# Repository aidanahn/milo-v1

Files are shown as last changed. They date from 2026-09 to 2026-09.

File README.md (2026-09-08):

# pacer-v1
A 3D-printed, 1/10-scale autonomous pacer robot for track and field.

## Videos
https://github.com/user-attachments/assets/b290baa9-71bd-49d5-837f-d4e4456bcb18

https://github.com/user-attachments/assets/f611f2c6-a903-4dcb-a009-24ee0bf0cf6d

## Bill of Materials
| Quantity | Part Name |
|:---:|---|
| 16 | 10x15x4mm Bearing |
| 2 | 5x10x4mm Bearing |
| 4 | M3 Tie Rod End |
| 1 | 35kg Servo |
| 1 | Servo Horn |
| 1 | Sensored Brushless DC Motor |
| 4 | Wheels |
| 1 | LiPo Battery |
| 1 | 120mm Timing Belt |
| 1 | 20T GT2 Timing Pulley |
| 1 | 40T GT2 Timing Pulley |
| 4 | 55mm Touring Shocks |
| 1 | Differential |
| 1 | Pinion Gear |
| 1 | Breadboard |
| 1 | ESP32-S3-DevKitC-1-N8R8 |
| 1 | Power Distribution Module |
| 1 | 5V Buck Converter |
| 1 | AS5600 |
| 1 | Diametrically Magnetized On-Axis Magnet |
| 1 | XT60 to T-Plug Adapter |
| 33 | Jumper Wires |
| 1 | 5V Buck Converter |
| | PETG Filament |
| | Differential Oil |
| | Shock Oil |

## Fastener List
| Type | Size | Length | Head | Quantity |
|---|---|---|---|---|
| Screw | M2 | 8mm | Button Head | 4 |
| Washer | M2 | | | 4 |
| Screw | M3 | 4mm | Socket Head | 10 |
| Screw | M3 | 8mm | Socket Head | 2 |
| Screw | M3 | 12mm | Socket Head | 21 |
| Screw | M3 | 16mm | Socket Head | 20 |
| Screw | M3 | 20mm | Socket Head | 6 |
| Screw | M3 | 25mm | Socket Head | 13 |
| Screw | M3 | 30mm | Socket Head | 1 |
| Screw | M3 | 35mm | Socket Head | 10 |
| Screw | M3 | 8mm | Button Head | 2 |
| Screw | M3 | 12mm | Button Head | 7 |
| Screw | M3 | 16mm | Button Head | 9 |
| Rod | M3 | 50mm | | 1 |
| Rod | M3 | 200mm | | 1 |
| Rod | M3 | | | 11 |
| Washer | M3 | | | 6 |
| Set Screw | M3 | | | 2 |
| Screw | M4 | 20mm | Socket Head | 4 |
| Nylon Locknut | M4 | | | 4 |

## License
This work is licensed under a [MIT License](LICENSE).

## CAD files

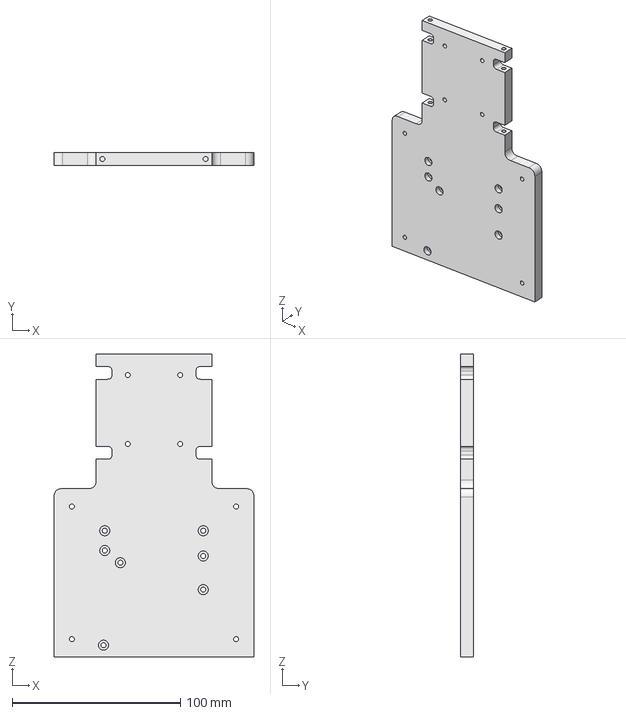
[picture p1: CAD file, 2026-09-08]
cad/chassis/front_plate.step
118.8 x 7.50 x 180.0 mm

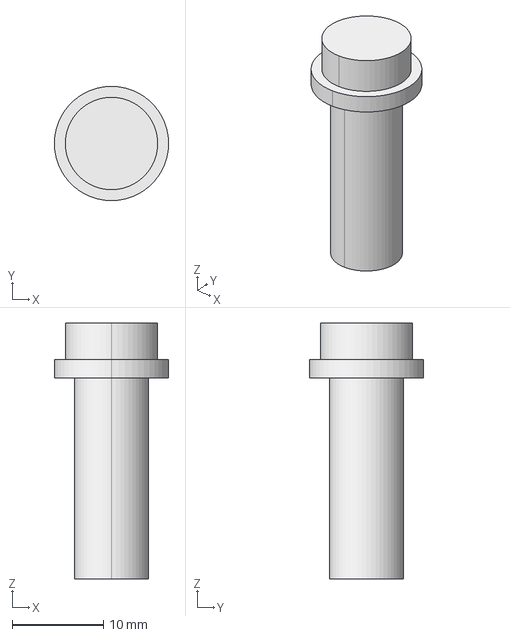
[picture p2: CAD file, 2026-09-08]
cad/drivetrain/shaft_coupling.step
12.5 x 12.5 x 28.0 mm

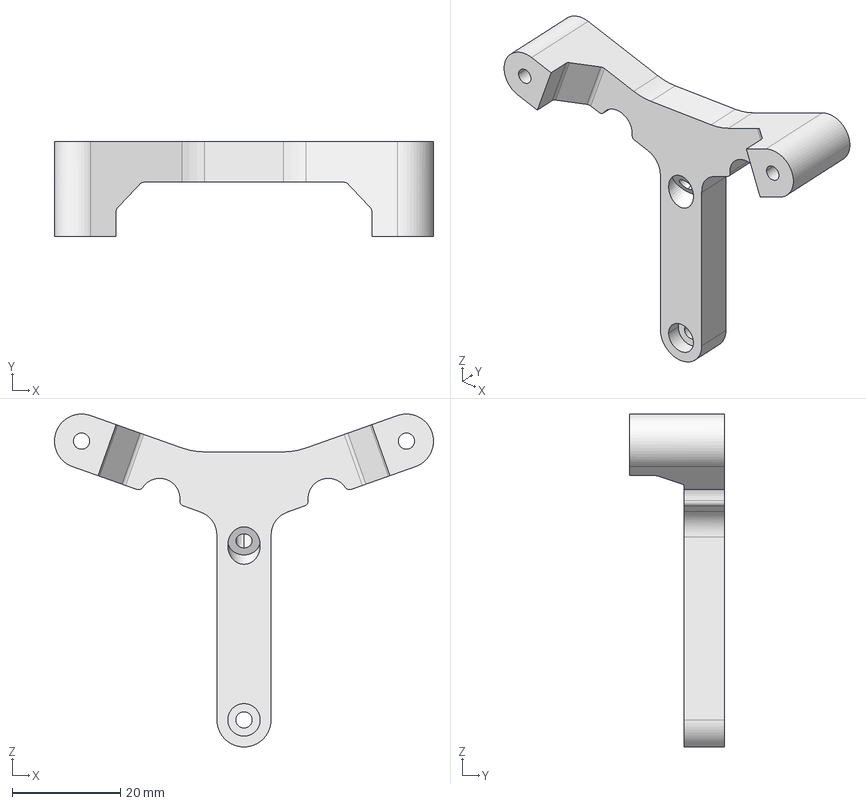
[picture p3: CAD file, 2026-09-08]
cad/sensors/sensor_arm.step
70.0 x 17.5 x 61.5 mm

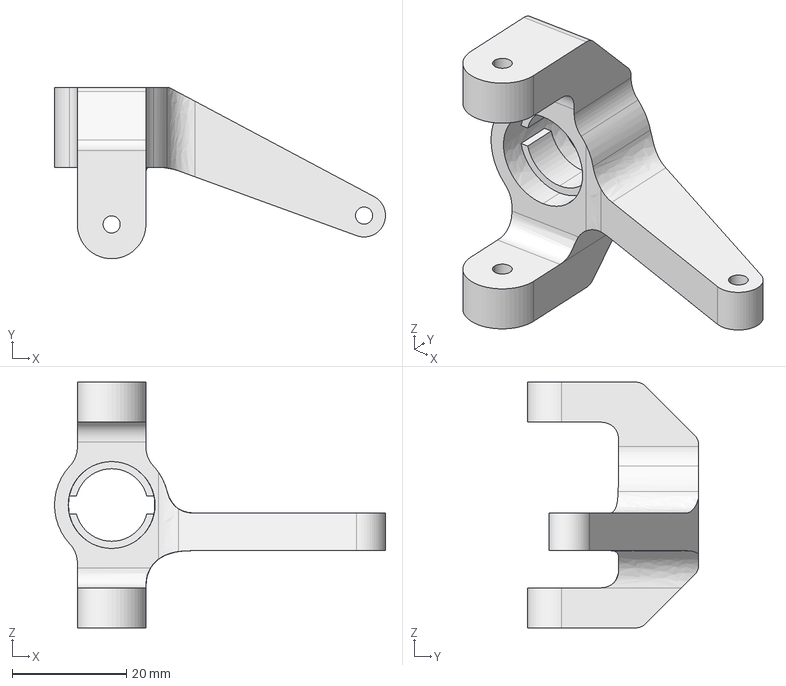
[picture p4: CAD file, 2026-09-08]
cad/steering/right_steering_knuckle.step
57.9 x 30.0 x 43.0 mm

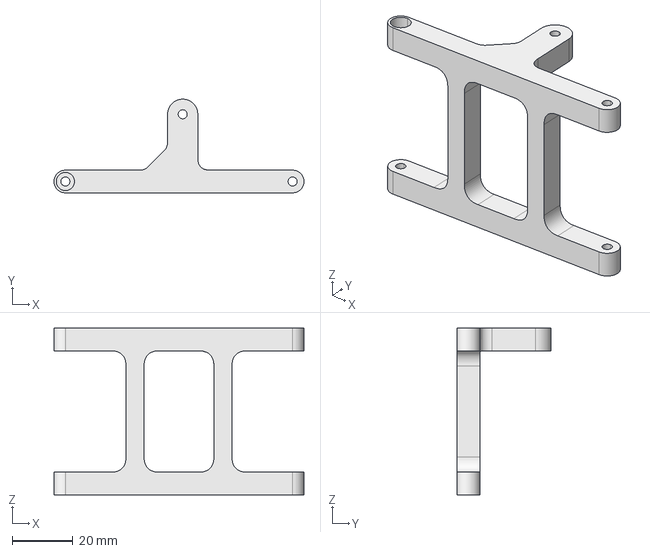
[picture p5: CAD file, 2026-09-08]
cad/suspension/rear_right_lower_control_arm.step
82.5 x 30.9 x 55.0 mm

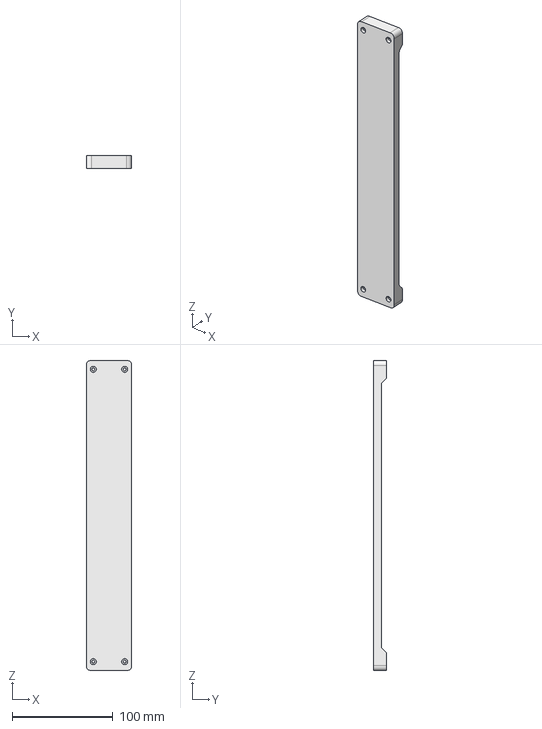
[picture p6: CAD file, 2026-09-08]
cad/chassis/electronics_bed.step
45.0 x 13.0 x 307.5 mm

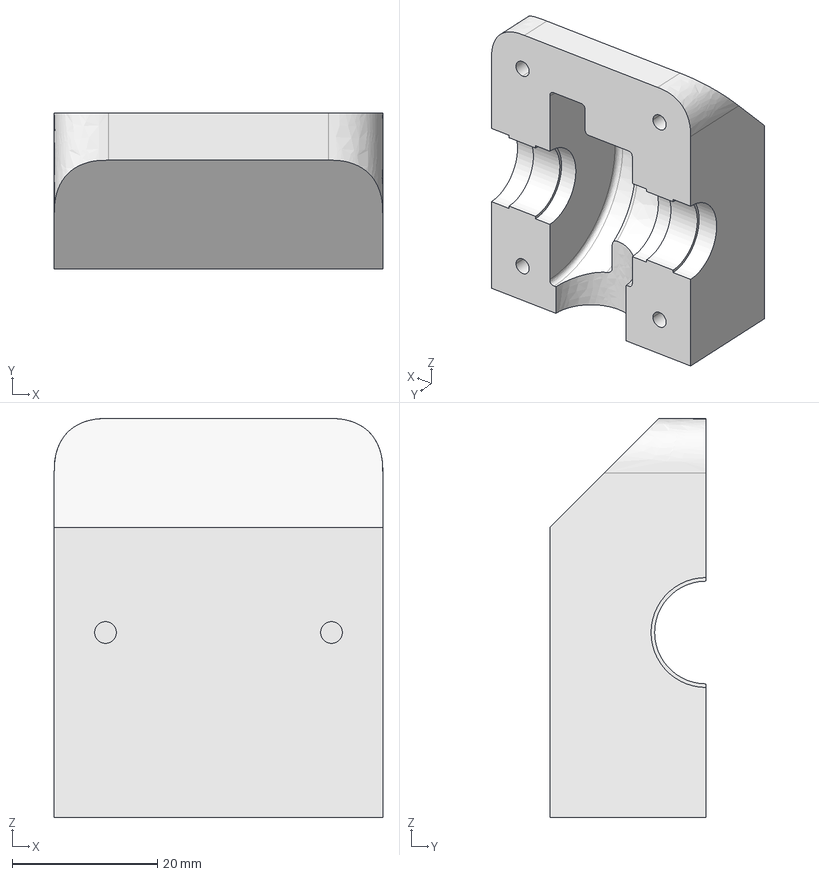
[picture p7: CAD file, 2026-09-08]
cad/drivetrain/upper_differential_case.step
45.3 x 21.5 x 55.0 mm

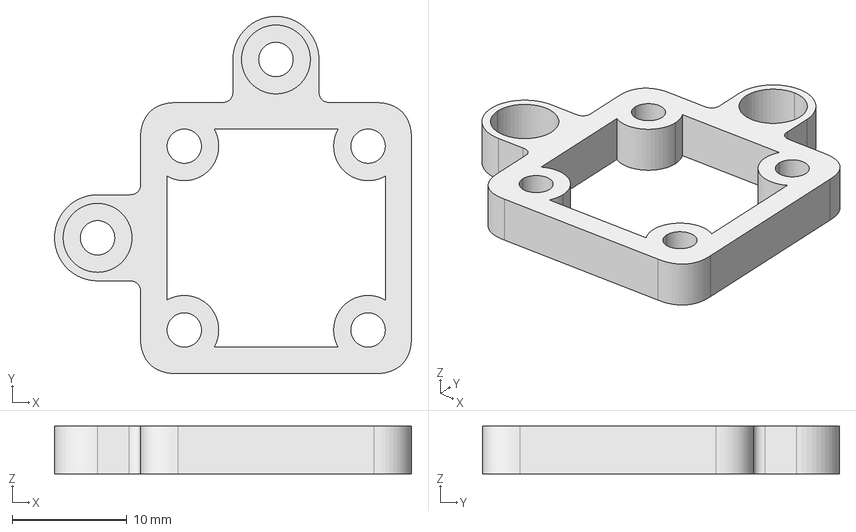
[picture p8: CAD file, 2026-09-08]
cad/sensors/as5600_mount.step
31.1 x 31.1 x 4.15 mm

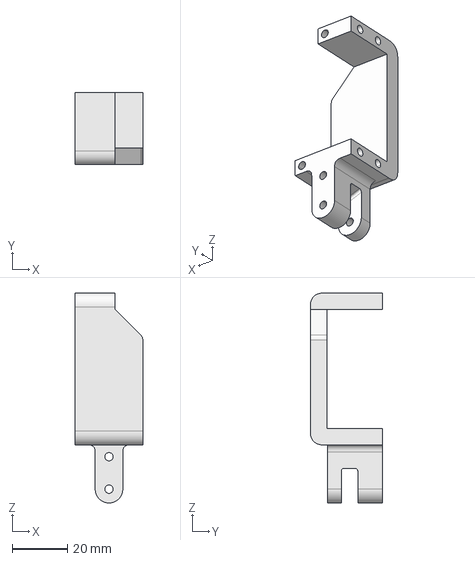
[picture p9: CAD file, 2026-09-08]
cad/steering/servo_mount.step
24.5 x 26.2 x 76.0 mm

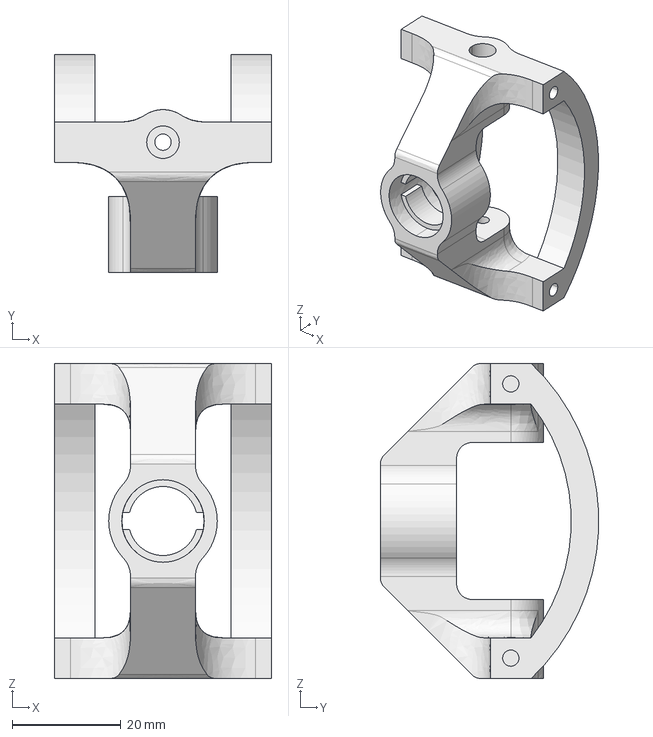
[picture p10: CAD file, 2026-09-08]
cad/suspension/rear_upright.step
40.0 x 40.2 x 58.0 mm

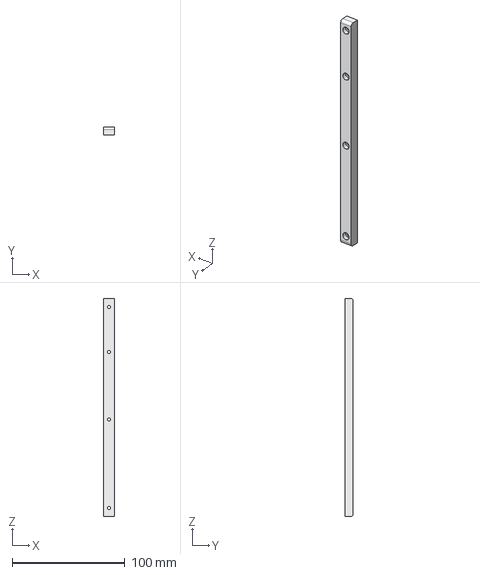
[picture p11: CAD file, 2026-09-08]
cad/chassis/right_reinforcement_beam.step
10.0 x 7.50 x 193.8 mm

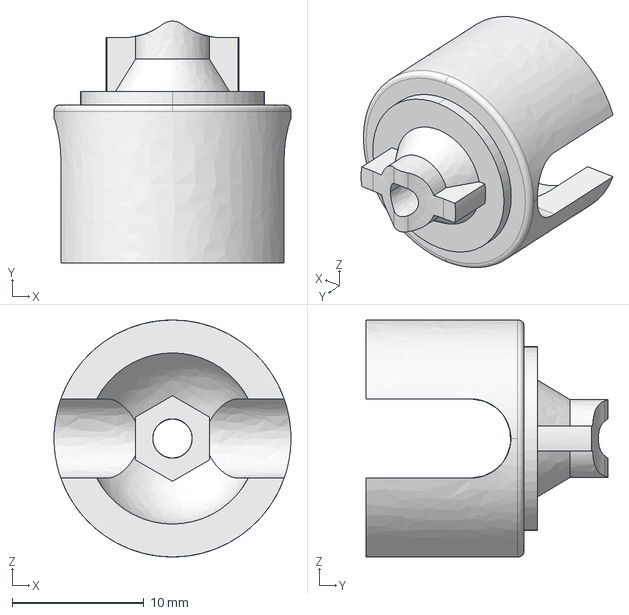
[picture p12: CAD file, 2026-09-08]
cad/drivetrain/upper_differential_cv_cup.step
18.0 x 18.4 x 18.0 mm

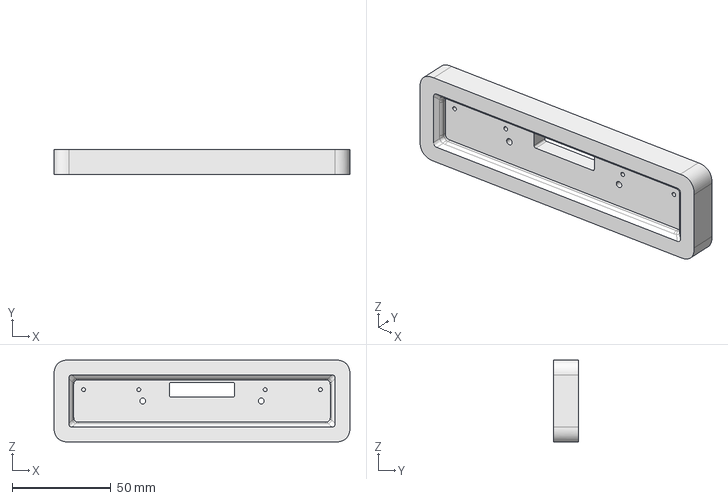
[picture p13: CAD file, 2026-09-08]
cad/sensors/sensor_mount.step
150.0 x 12.5 x 41.5 mm

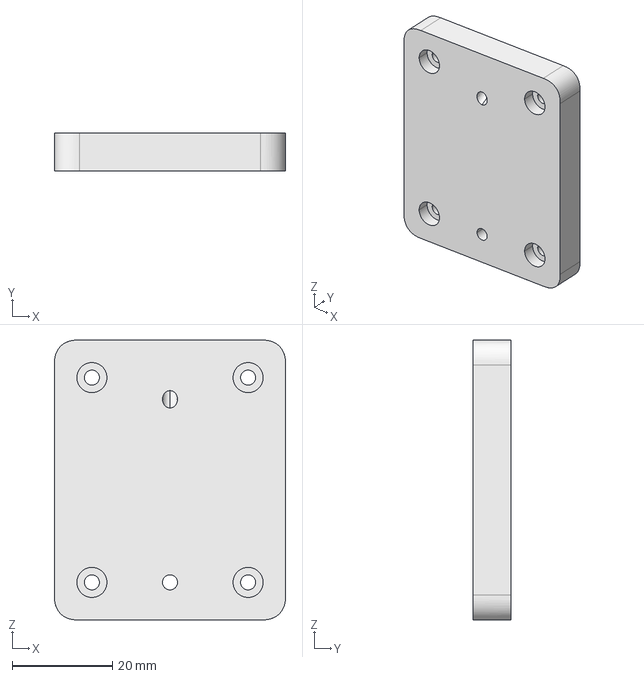
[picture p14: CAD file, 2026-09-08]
cad/steering/servo_mounting_plate.step
46.2 x 7.50 x 55.9 mm

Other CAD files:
cad/suspension/upper_control_arm.step
cad/chassis/left_reinforcement_beam.step
cad/drivetrain/wheel_hub.step
cad/steering/steering_linkage.step
cad/chassis/rear_plate.step
cad/drivetrain/cv_axle.step
cad/drivetrain/cv_cup.step
cad/drivetrain/differential_case_backplate.step
cad/drivetrain/driveshaft.step
cad/drivetrain/front_gearbox_cover.step
cad/drivetrain/front_gearbox_cup.step
cad/drivetrain/lower_differential_case.step
cad/drivetrain/lower_differential_cv_cup.step
cad/drivetrain/rear_gearbox_cover.step
cad/drivetrain/rear_gearbox_cup.step
cad/steering/left_steering_knuckle.step
cad/steering/servo_linkage.step
cad/steering/steering_bar.step
cad/steering/steering_mount.step
cad/suspension/front_left_lower_control_arm.step
cad/suspension/front_right_lower_control_arm.step
cad/suspension/front_upright.step
cad/suspension/rear_left_lower_control_arm.step
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

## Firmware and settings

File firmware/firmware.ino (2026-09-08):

/**
 * @file firmware.ino
 * @brief Initialize hardware and coordinate the Pacer feedback-control loop.
 *
 * Connects QTR line sensing and AS5600 odometry to steering and velocity PID
 * controllers. WebInterface dispatches run commands to the callbacks here;
 * PacerController applies actuator outputs and handles distance completion.
 */

#include <Arduino.h>
#include "as5600.hpp"
#include "pacer_controller.hpp"
#include <QTRSensors.h>
#include <Adafruit_NeoPixel.h>
#include "config.hpp"
#include "web_interface.hpp"
#include <PID_v1.h>

uint16_t sensorValues[config::SENSOR_COUNT];
PacerSettings settings;
double velocityInput, velocityOutput, velocitySetpoint;
double steeringInput, steeringOutput, steeringSetpoint;

PID velocityPID(&velocityInput, &velocityOutput, &velocitySetpoint, settings.velocityKp, settings.velocityKi, settings.velocityKd, DIRECT);
PID steeringPID(&steeringInput, &steeringOutput, &steeringSetpoint, settings.steeringKp / 1000, settings.steeringKi / 1000, settings.steeringKd / 1000, REVERSE);
AS5600 as5600("REVERSE", config::GEAR_RATIO, config::WHEEL_CIRCUMFERENCE);
Adafruit_NeoPixel strip(config::LED_COUNT, config::LED_PIN, NEO_GRB + NEO_KHZ800);
PacerController pacer(config::ESC_PIN, config::SERVO_PIN, config::GEAR_RATIO, config::WHEEL_CIRCUMFERENCE, strip);
WebInterface web(settings);
QTRSensors qtr;

void debug();
void handleStart();
void handleStop();
void handleCalibrate();
void handlePID();

/**
 * @brief Initialize serial output, control loops, web routes, and hardware.
 * @details Configures both PID controllers with a 20 ms sample interval.
 * Sensor calibration is performed separately through the web interface.
 */
void setup() {
  Serial.begin(921600);

  velocityPID.SetSampleTime(20);
  velocityPID.SetOutputLimits(0, 500);
  velocityPID.SetMode(AUTOMATIC);
  steeringSetpoint = 7500;
  steeringPID.SetSampleTime(20);
  steeringPID.SetOutputLimits(-90, 90);
  steeringPID.SetMode(AUTOMATIC);

  web.begin(handleStart, handleStop, handleCalibrate, handlePID);

  qtr.setTypeRC();
  qtr.setSensorPins(config::SENSOR_PINS, config::SENSOR_COUNT);
  qtr.setDimmingLevel(0);
  qtr.setTimeout(3000);

  as5600.begin();

  pacer.begin();
}

/**
 * @brief Service web requests and update feedback control while pacing.
 * @details Encoder and line-sensor readings feed the velocity and steering
 * controllers. PID Compute() calls respect their configured sample intervals;
 * the Arduino loop itself does not run at a fixed frequency.
 */
void loop() {
  web.update();
  if (pacer.getPacingStatus()) {
    as5600.update();

    debug();

    steeringInput = qtr.readLineWhite(sensorValues);
    steeringPID.Compute();
    velocityInput = as5600.getRotationsPerSecond();
    velocityPID.Compute();

    pacer.update(steeringOutput, velocityOutput, as5600.getDistanceTraveled());
  }
}

/**
 * @brief Write encoder speed to serial between fixed plot references.
 * @details Emits CSV values: 20, encoder-shaft rotations per second, 30.
 * The outer values are plotting references, not measured speeds.
 */
void debug() {
  Serial.print("20");
  Serial.print(",");
  Serial.print(as5600.getRotationsPerSecond());
  Serial.print(",");
  Serial.println("30");
}

/**
 * @brief Start a run using the current distance and duration settings.
 * @details Resets distance accumulation and reinitializes both PID controllers
 * with zero output. Sets the velocity target in encoder-shaft rotations per
 * second. WebInterface updates settings before invoking this callback.
 */
void handleStart() {
  as5600.resetDistanceTraveled();
  velocityPID.SetMode(MANUAL);
  velocityOutput = 0;
  velocityPID.SetMode(AUTOMATIC);
  steeringPID.SetMode(MANUAL);
  steeringOutput = 0;
  steeringPID.SetMode(AUTOMATIC);
  pacer.start(settings.distance, settings.pace);
  velocitySetpoint = pacer.getGoalRotationsPerSecond();
}

/**
 * @brief Stop pacing and restore neutral throttle and centered steering.
 */
void handleStop() {
  pacer.stop();
}

/**
 * @brief Reset and collect 400 calibration samples from the QTR array.
 * @details Shows yellow during calibration and green afterward. This callback
 * blocks web servicing and the main control loop until sampling completes;
 * the sensor array must encounter the line and background during sampling.
 */
void handleCalibrate() {
  qtr.resetCalibration();
  pacer.setStatusColor(255, 255, 0);
  for (uint16_t i = 0; i < 400; i++) {
    qtr.calibrate();
  }
  pacer.setStatusColor(0, 255, 0);
}

/**
 * @brief Apply the current web-editable gains to both PID controllers.
 * @details Steering gains are divided by 1000 to match the QTR position scale;
 * velocity gains are applied directly. WebInterface updates the settings first.
 */
void handlePID() {
  steeringPID.SetTunings(settings.steeringKp / 1000, settings.steeringKi / 1000, settings.steeringKd / 1000);
  velocityPID.SetTunings(settings.velocityKp, settings.velocityKi, settings.velocityKd);
}

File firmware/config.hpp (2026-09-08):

/**
 * @file config.hpp
 * @brief Hardware constants and initial values for web-editable settings.
 */

#ifndef PACER_FIRMWARE_CONFIG_HPP_
#define PACER_FIRMWARE_CONFIG_HPP_

#include <Arduino.h>

/// Hardware mapping and network configuration for the current vehicle.
namespace config {
/// Wheel circumference in meters, derived from a 121.9 mm diameter.
const double WHEEL_CIRCUMFERENCE = PI * (121.9 / 1000.0);
/// Encoder-shaft revolutions per wheel revolution across both gear stages.
const double GEAR_RATIO = (40.0 / 20.0) * (38.0 / 13.0);
const uint8_t LED_COUNT = 1;
const uint8_t LED_PIN = 38;
const uint8_t SENSOR_COUNT = 16;
/// GPIO sequence supplied to QTRSensors; order determines the position scale.
const uint8_t SENSOR_PINS[] = { 48, 10, 39, 40, 41, 42, 2, 1, 18, 17, 16, 15, 7, 6, 5, 4 };
const uint8_t ESC_PIN = 21;
const uint8_t SERVO_PIN = 47;
const char* const SSID = "PacerESP32";
const char* const PASSWORD = "04082008";

}  // namespace config

/**
 * @brief Initial run settings and PID gains, held in RAM and editable over HTTP.
 * @details Changes are not persisted across resets. Steering gains are divided
 * by 1000 before application; velocity gains are passed to PID_v1 unchanged.
 */
struct PacerSettings {
  /// Target run distance in meters.
  int distance = 400;
  /// Target duration in seconds for the full run distance.
  int pace = 60;
  double velocityKp = 1.0;
  double velocityKd = 0.0;
  double velocityKi = 2.5;
  double steeringKp = 5.0;
  double steeringKd = 1.1;
  double steeringKi = 0.0;
};

#endif

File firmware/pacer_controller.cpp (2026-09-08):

/**
 * @file pacer_controller.cpp
 * @brief ESP32 PWM output, status indication, and run completion logic.
 */

#include "pacer_controller.hpp"

PacerController::PacerController(int escPin, int servoPin, double gearRatio, double wheelCircumference, Adafruit_NeoPixel& strip) 
  : strip(strip)
{
  this->escPin = escPin;
  this->servoPin = servoPin;
  this->isPacing = false;
  this->gearRatio = gearRatio;
  this->wheelCircumference = wheelCircumference;
}

void PacerController::setESCMicroseconds(int microseconds) {
  microseconds = constrain(microseconds, 1000, 2000);
  // Scale pulse width by the 14-bit duty range over a 20 ms PWM period.
  ledcWrite(escPin, microseconds * 16383 / 20000);
}

void PacerController::setServoAngle(int angle) {
  angle = constrain(angle, 0, 180);
  int microseconds = map(angle, 0, 180, 1000, 2000);
  ledcWrite(servoPin, microseconds * 16383 / 20000);
}

void PacerController::resetControls() {
  setESCMicroseconds(1500);
  setServoAngle(90);
  setStatusColor(0, 255, 0);
}

void PacerController::begin() {
  ledcAttach(escPin, FREQUENCY, RESOLUTION);
  ledcAttach(servoPin, FREQUENCY, RESOLUTION);
  resetControls();
  setStatusColor(0, 255, 0);
}

void PacerController::update(double steeringOutput, double velocityOutput, double distanceTraveled) {
  // The 1575 us baseline is specific to the current ESC setup.
  setESCMicroseconds(1575 + (int)velocityOutput);
  setServoAngle(90 + (int)steeringOutput);
  if (distanceTraveled >= distance) {
    stop();
  }
}

void PacerController::setStatusColor(uint8_t r, uint8_t g, uint8_t b) {
  strip.setPixelColor(0, r, g, b);
  strip.show();
}

void PacerController::start(int distance, int pace) {
  this->distance = distance;
  this->pace = pace;
  calculateGoalRotationsPerSecond();
  setStatusColor(255, 255, 255);
  isPacing = true;
}

void PacerController::stop() {
  resetControls();
  isPacing = false;
}

bool PacerController::getPacingStatus() {
  return isPacing;
}

void PacerController::calculateGoalRotationsPerSecond() {
  goalRotationsPerSecond = (distance / (pace * wheelCircumference)) * gearRatio;
}

double PacerController::getGoalRotationsPerSecond() {
  return goalRotationsPerSecond;
}

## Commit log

2026-01-04 Change QTR sensor reading from black to white
2026-09-08 Replace CAD models with updated STEP files
    [Assembly 1 - AS5600 Mount.step, Assembly 1 - CV Axle.step, Assembly 1 - CV Cup.step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]
2026-09-08 Organize CAD models by mechanical subsystem
    [as5600_mount.step, cv_axle.step, cv_cup.step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]
2026-09-08 Add Bill of Materials to README
    Added a Bill of Materials section with detailed parts list.
